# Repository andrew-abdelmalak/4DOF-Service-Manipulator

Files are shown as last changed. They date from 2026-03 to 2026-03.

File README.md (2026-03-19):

# 4-DOF Service Robotic Manipulator for Automated Beverage Preparation








<p align="center">
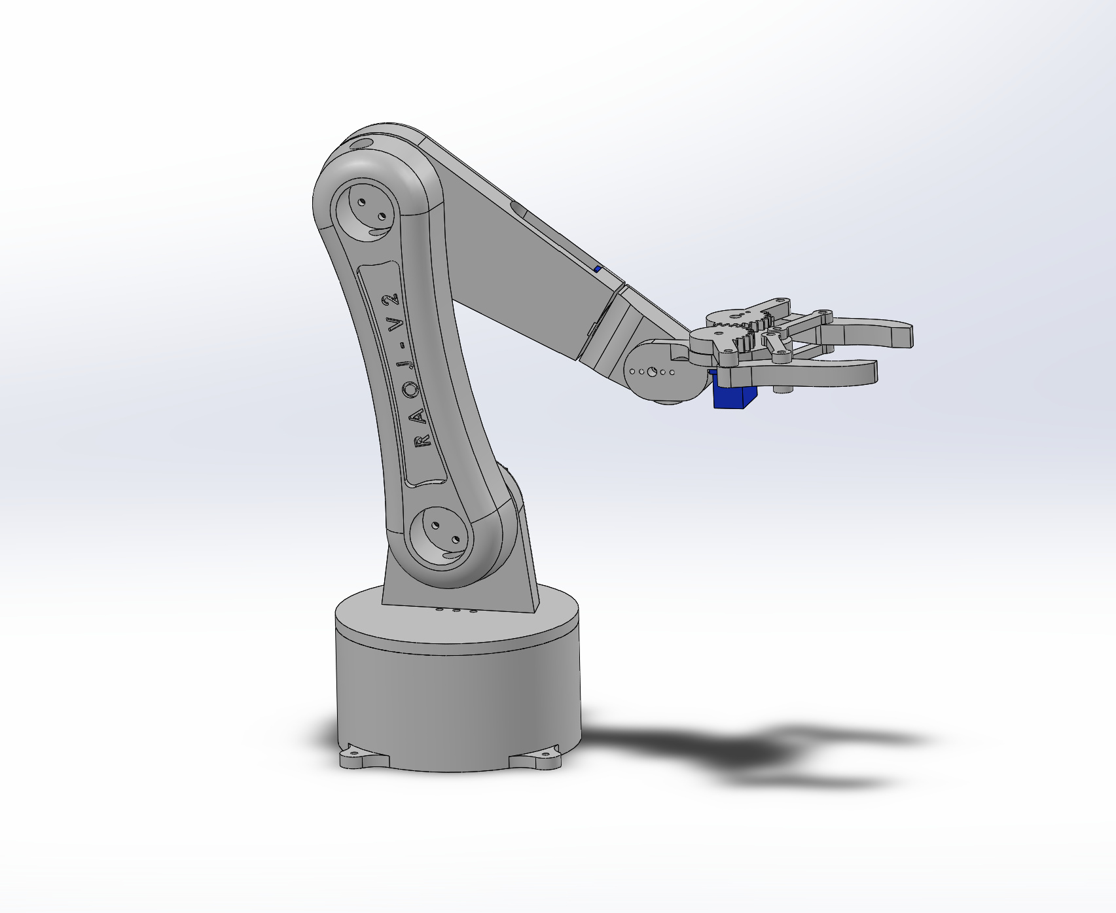
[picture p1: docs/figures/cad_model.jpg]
CAD model of the 4-DOF robotic manipulator
  
</p>

A desktop-scale **4-DOF service robotic manipulator** designed for **automated beverage preparation**. The system covers the full robotics development pipeline — from DH-based kinematic modeling through dual-platform simulation (Gazebo + Simscape) to physical hardware execution on a 3D-printed arm.

The robot performs a complete **tea-preparation demo**: sugar transport, spoon manipulation, and stirring — demonstrating coordinated multi-step service tasks using open-loop trajectory control.

> **Paper:** The full IEEE-format technical report is available in [`docs/4DOF_Service_Manipulator.pdf`](docs/4DOF_Service_Manipulator.pdf).

---

## Table of Contents

- [Overview](#overview)
- [System Architecture](#system-architecture)
- [Simulation & Results](#simulation--results)
- [Tea-Preparation Demo](#tea-preparation-demo)
- [Repository Structure](#repository-structure)
- [Getting Started](#getting-started)
- [Authors](#authors)
- [License](#license)

---

## Overview

The manipulator has 5 revolute joints (4 active DOF + 1 gripper joint), constructed from **3D-printed PLA** and actuated by **MG996R** (high-torque) + **SG90** (micro) servo motors. Control is handled by an Arduino Uno communicating with a PC-based trajectory planner over serial (115 200 baud).

<p align="center">
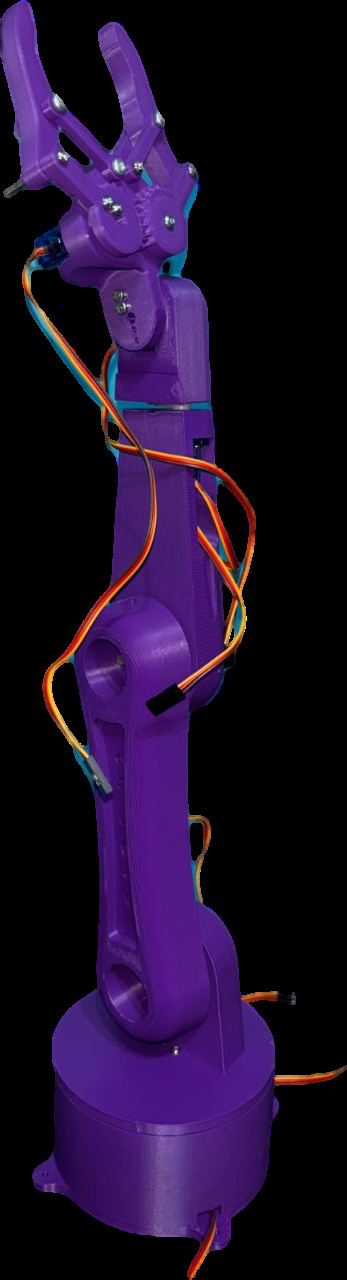
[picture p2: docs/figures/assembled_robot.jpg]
Fully assembled 4-DOF manipulator
  
</p>

### DH Parameters

Coordinate frames follow the Denavit–Hartenberg convention with the X–Z rule.

<p align="center">
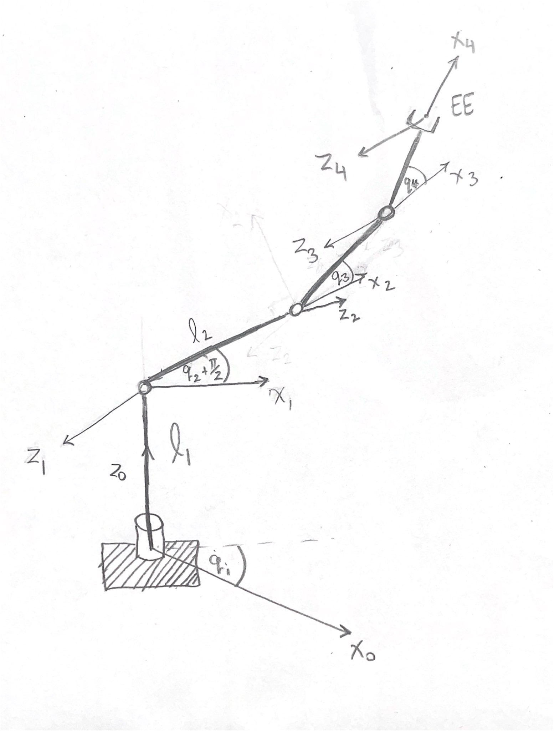
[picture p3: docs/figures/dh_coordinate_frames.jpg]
DH coordinate frame assignment
  
</p>

| Link | θᵢ | dᵢ (m) | aᵢ (m) | αᵢ (rad) |
|---|-----|---|---|---|
| 1 | q₁ + π/2 | 0.04355 | 0 | π/2 |
| 2 | q₂ | 0 | 0.140 | π |
| 3 | q₃ | 0 | 0.133 | π |
| 4 | q₄ | 0 | 0.109 | 0 |

### Key Results

| Metric | Value |
|---|---|
| FK roundtrip positional error | 0.000 m |
| IK roundtrip velocity error | ~10⁻¹⁵ (machine precision) |
| Zero-config end-effector height | 0.4255 m (= d₁ + a₂ + a₃ + a₄) |
| Trajectory sampling period | 0.1 s |
| IK damping factor (λ) | 0.05 |

---

## System Architecture

| Component | Qty | Role |
|---|-----|---|
| 3D-printed PLA parts | 1 set | Arm structure |
| MG996R servo motors | 3 | Base, shoulder, elbow (high-torque) |
| SG90 micro servos | 3 | Wrist, gripper, fixed pivot |
| Arduino Uno | 1 | PWM servo control |
| 12 V DC power supply | 1 | Motor power |

<p align="center">
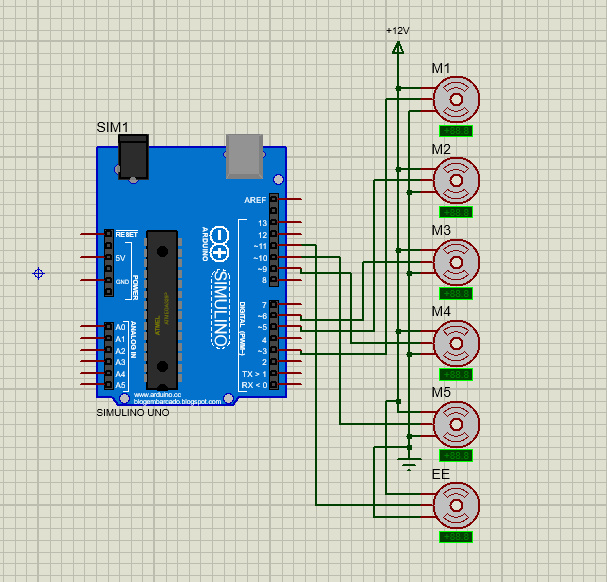
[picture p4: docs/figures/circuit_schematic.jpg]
Circuit schematic
  
</p>

**Communication protocol:** The PC-based trajectory planner sends comma-separated joint angles (`"J1,J2,J3,J4\n"`) over serial at 115 200 baud. The Arduino responds with `"READY\n"` after each command to ensure motion synchronization. Dedicated `GRIPPER_OPEN` / `GRIPPER_CLOSE` commands control the end-effector.

---

## Simulation & Results

Kinematic models and trajectories were validated on two independent simulation platforms, plus physical hardware:

<p align="center">
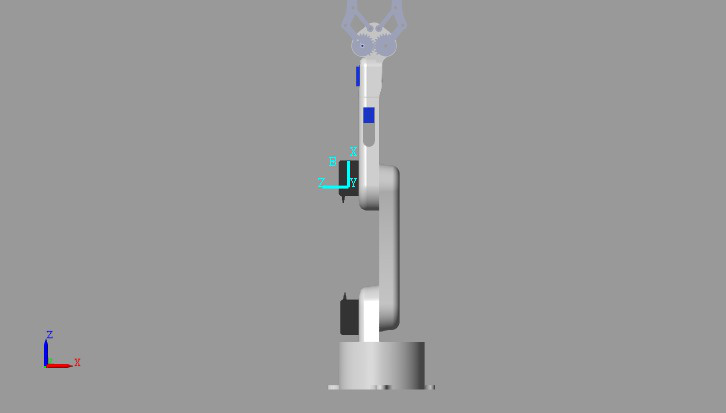
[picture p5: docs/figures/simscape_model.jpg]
Simscape Multibody model
  
  &nbsp;&nbsp;
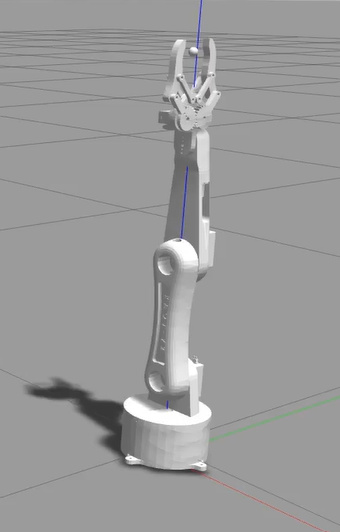
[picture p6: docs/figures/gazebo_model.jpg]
Gazebo simulation
  
</p>
<p align="center"><em>Left: Simscape Multibody &nbsp;|&nbsp; Right: Gazebo/ROS</em></p>

**Trajectory validation** — both square (pick-and-place) and circular (stirring) trajectories were executed across all platforms with high fidelity:

<p align="center">
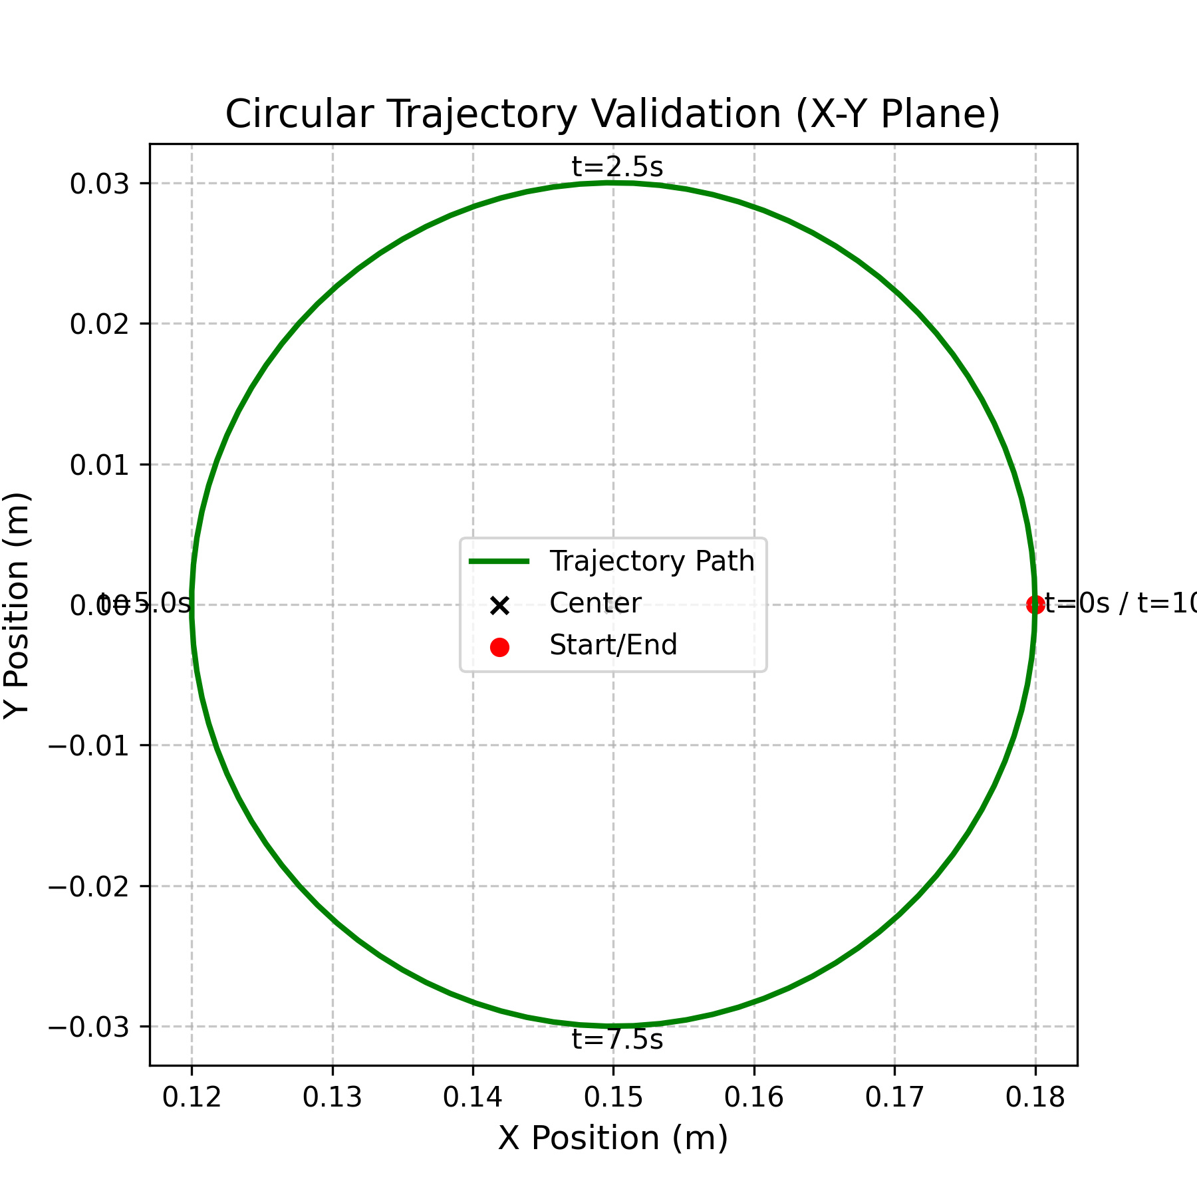
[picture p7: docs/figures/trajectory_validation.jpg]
Circular trajectory validation
  
  &nbsp;&nbsp;
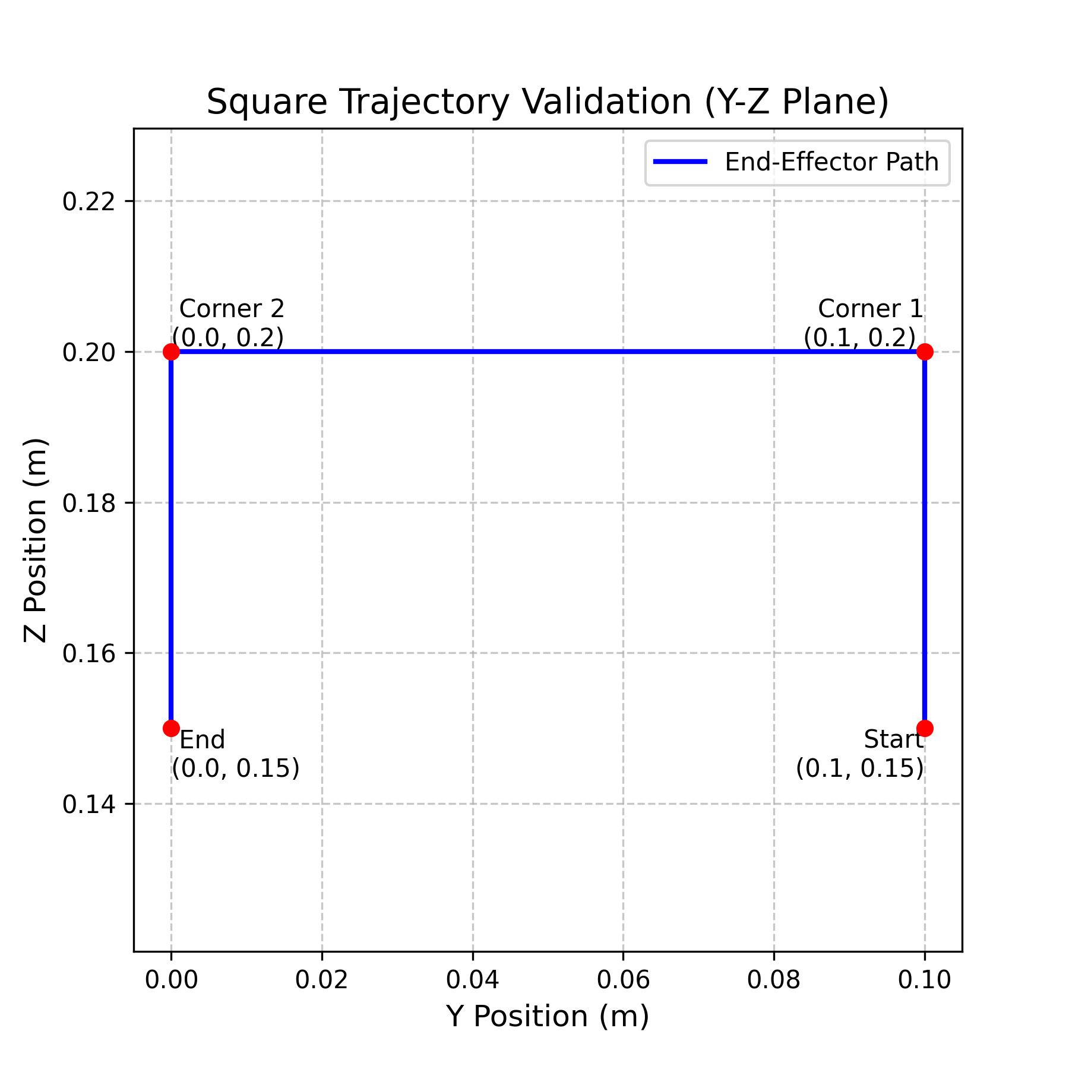
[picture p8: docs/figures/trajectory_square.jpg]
Square trajectory validation
  
</p>
<p align="center"><em>Left: Circular trajectory &nbsp;|&nbsp; Right: Square trajectory</em></p>

| Test | Input q (rad) | ‖q_rec − q‖ | ‖q̇_rec − q̇‖ |
|---|---|---|---|
| Case 1 | [0, 0, 0, 0] | 0.000 | 0.000 |
| Case 2 | [0.2, 0.4, −0.3, 0.1] | 0.000 | 1.38×10⁻¹⁵ |
| Case 3 | [−0.3, 0.6, 0.2, −0.2] | 0.000 | 5.49×10⁻¹⁶ |

---

## Tea-Preparation Demo

The primary validation task demonstrates coordinated task-space motion and gripper actuation across five sequential phases:

| Phase | Motion | Points | Description |
|---|---|---|---|
| 1 | Square path 1 | 104 | Pick up sugar cube, transport to cup, release |
| 2 | Square path 2 | 104 | Move end-effector to spoon and grasp handle |
| 3 | Reverse square | 104 | Lift spoon, transport toward cup |
| 4 | Linear transition | 42 | Center spoon inside cup |
| 5 | Circular stirring | 102 × 3 | Stir for three full cycles (30 s total) |

<p align="center">
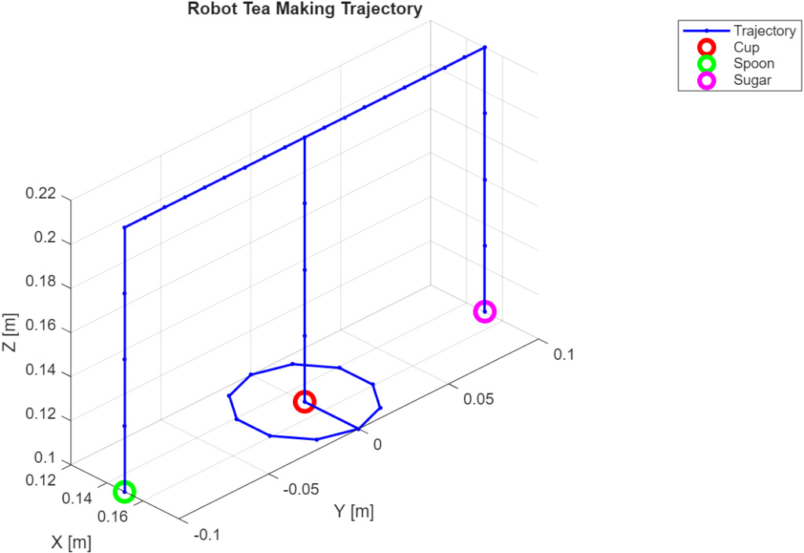
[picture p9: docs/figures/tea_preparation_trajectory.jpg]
3D tea-preparation trajectory visualization
  
</p>
<p align="center"><em>3D visualization of the complete tea-preparation trajectory showing waypoints for sugar transport, spoon approach, and stirring.</em></p>

---

## Repository Structure

```
├── simulation/
│   ├── ros/src/                        # ROS/Gazebo simulation
│   │   └── my_robot_gazebo/            # ROS package
│   │       ├── urdf/robot.urdf         # Robot description
│   │       ├── launch/                 # Gazebo launch files
│   │       ├── meshes/                 # STL mesh files
│   │       ├── config/                 # Controller configs
│   │       ├── scripts/                # Python nodes (FK, IK, trajectory)
│   │       ├── models/                 # Gazebo world models
│   │       └── worlds/                 # Gazebo world files
│   │
│   └── matlab/                         # MATLAB/Simulink
│       ├── kinematics/                 # FK, IK, Jacobian functions
│       ├── trajectory/                 # Trajectory planners + CSV data
│       ├── simscape/                   # Simulink Simscape Multibody model
│       └── tests/                      # Validation scripts
│
├── hardware/
│   ├── arduino/                        # Arduino servo control
│   │   ├── receiver/receiver.ino       # Arduino firmware
│   │   ├── send_trajectory.py          # PC → Arduino trajectory sender
│   │   └── trajectories/              # Pre-computed CSV joint angles
│   │
│   ├── cad/                            # SolidWorks CAD exports
│   │   ├── 5_DOF_Robot_Assembly.SLDASM # Full assembly
│   │   └── *.STEP                      # Individual part files
│   └── actuator_connections.pdsprj     # Proteus circuit simulation
│
├── docs/
│   ├── 4DOF_Service_Manipulator.pdf    # Full IEEE-format technical report
│   └── figures/                        # Figures from the report
│
├── .gitignore
├── LICENSE
├── README.md
└── requirements.txt
```

---

## Getting Started

### Prerequisites

| Tool | Version | Purpose |
|---|---|---|
| ROS Noetic | Ubuntu 20.04 | Gazebo simulation |
| MATLAB | R2023b+ | Kinematics + Simscape |
| Python | 3.8+ | ROS nodes + Arduino comm |
| Arduino IDE | 2.0+ | Firmware upload |

### Python Environment

```bash
python -m venv .venv
source .venv/bin/activate        # Linux/macOS
# .venv\Scripts\activate         # Windows
pip install -r requirements.txt
```

### ROS / Gazebo

```bash
mkdir -p ~/catkin_ws/src
ln -s /path/to/this/repo/simulation/ros/src/my_robot_gazebo ~/catkin_ws/src/
cd ~/catkin_ws && catkin_make && source devel/setup.bash

# Launch robot in Gazebo
roslaunch my_robot_gazebo spawn_gazebo.launch

# Run trajectory execution (separate terminal)
rosrun my_robot_gazebo trajectory_node.py
```

### MATLAB / Simulink

```matlab
addpath('simulation/matlab/kinematics');
addpath('simulation/matlab/trajectory');
addpath('simulation/matlab/tests');

test_forward_position     % FK validation
test_inverse_kinematics   % IK validation
test_velocity_kinematics  % Jacobian validation

% Open Simscape model
open('simulation/matlab/simscape/x5_DOF_Robot_Assembly.slx')
```

See [`simulation/matlab/README.md`](simulation/matlab/README.md) for detailed usage.

### Arduino Hardware

1. Upload `hardware/arduino/receiver/receiver.ino` to the Arduino Uno
2. Connect servos to PWM pins (Base→3, Shoulder→5, Elbow→6, Wrist→9, Gripper→10)
3. Set the serial port in `send_trajectory.py` (`/dev/cu.usbserial-110` on macOS, `COM3` on Windows)
4. Run: `python hardware/arduino/send_trajectory.py`

See [`hardware/arduino/README.md`](hardware/arduino/README.md) for detailed setup, calibration, and troubleshooting.

---

## Authors

| Name | Affiliation |
|---|---|
| **Andrew Abdelmalak** | Mechatronics Engineering, GUC |
| **Daniel Boules** | Mechatronics Engineering, GUC |
| **David Girgis** | Mechatronics Engineering, GUC |
| **Kirolous Kirolous** | Mechatronics Engineering, GUC |
| **Samir Yacoub** | Mechatronics Engineering, GUC |
| **Youssef Salama** | Mechatronics Engineering, GUC |

---

## Acknowledgments

This project was developed as part of the Mechatronics Engineering program at the German University in Cairo (GUC).

---

## References

1. S. Park *et al.*, "Robot versus human barista: Comparison of volatile compounds and consumers' acceptance, sensory profile, and emotional response of brewed coffee," *Food Research International*, vol. 172, p. 113119, 2023.
2. A. Setiawan and A. Ma'arif, "Stirring system design for automatic coffee maker using OMRON PLC and PID control," *Int. J. Robotics and Control Systems*, vol. 1, no. 1, pp. 1–8, 2021.
3. M. Michalková *et al.*, "Automating the handling process of a coffee machine using a robotic manipulator," in *Proc. IEEE Int. Conf. ETFA*, 2024.
4. H. P. Nurba *et al.*, "Performance evaluation of 3 DOF arm robot with forward kinematics Denavit–Hartenberg method," in *Proc. IEEE TSSA*, 2022.
5. H. D. Salman, M. N. Hamzah, and S. H. Bakhy, "Kinematics analysis and implementation of three degrees of freedom robotic arm by using MATLAB," *The Iraqi Journal for Mechanical and Material Engineering*, vol. 21, no. 2, pp. 118–129, 2021.
6. M. A. Saad *et al.*, "Development of an automated coffee preparation system using a robotic manipulator," *J. Mechatronics, Robotics, and Systems Programming*, vol. 31, no. 38, pp. 45–52, 2024.
7. A. Waluyo *et al.*, "Robot arm design for coffee maker Arduino based," in *Proc. 2nd Borobudur Int. Symposium on Science and Technology*, Atlantis Press, 2021, pp. 438–442.
8. J. J. Craig, *Introduction to Robotics: Mechanics and Control*, 3rd ed. Pearson Prentice Hall, 2005.
9. B. Siciliano *et al.*, *Robotics: Modelling, Planning and Control*. Springer, 2009.

---

## License

MIT — see [LICENSE](LICENSE).

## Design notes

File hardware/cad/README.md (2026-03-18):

# CAD Files

SolidWorks CAD design files for the 4-DOF service robotic manipulator.

## Assembly

- **`5_DOF_Robot_Assembly.SLDASM`** — Full SolidWorks assembly (requires SolidWorks 2020+)

## Part Files (STEP)

Individual part exports in STEP format (universal, compatible with any CAD software):

| Part | Description |
|---|---|
| Base Link | Stationary base housing the MG996R base servo |
| Arm 1 (Shoulder) | First link driven by the shoulder servo |
| Arm 2 (Elbow) | Second link driven by the elbow servo |
| Arm 3 (Wrist) | Wrist link driven by SG90 micro servo |
| Gripper | Parallel-jaw gripper with friction-lined inner surfaces |
| Rotating Waste | Fixed pivot component (maintains 4-DOF kinematic chain) |

## Manufacturing

- **Material:** PLA (3D-printed on FDM printer)
- **Servos:** 3× MG996R (base, shoulder, elbow) + 3× SG90 (wrist, gripper, fixed pivot)
- **Assembly:** Servo horns press-fit into 3D-printed brackets; base secured to weighted wooden board

## Mesh Exports

STL mesh files used for Gazebo/RViz visualization are located at:

```
simulation/ros/src/my_robot_gazebo/meshes/
```

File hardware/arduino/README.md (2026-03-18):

# 🤖 Tea-Making Robot Arm - User Guide

## 📋 Overview

This project controls a **4-DOF (4 Degrees of Freedom) robotic arm** designed to perform automated tea-making tasks. The robot features **4 joints** for precise movement and a **gripper** (not counted as a DOF) for object manipulation.

### Robot Specifications
- **Degrees of Freedom:** 4 (Joints 1-4)
- **End Effector:** 1 Gripper (Joint 5)
- **Control:** Serial communication via Arduino
- **Function:** Automated tea preparation and serving

---

## 🎯 System Components

### Hardware
1. **Arduino Board** (with servo connections)
2. **5 Servo Motors:**
   - Joint 1-4: Robot arm movement (4-DOF)
   - Joint 5: Gripper for grasping objects
3. **USB Cable** for Arduino-to-Computer connection

### Software Files
1. **`receiver.ino`** - Arduino firmware (runs on Arduino)
2. **`send_trajectory.py`** - Python trajectory controller (runs on computer)
3. **CSV Trajectory Files** (in `trajectories/` folder):
   - `trajectory_data_combined_1_square1.csv`
   - `trajectory_data_combined_2_square2.csv`
   - `trajectory_data_combined_3_square2_rev.csv`
   - `trajectory_data_combined_4_transition.csv`
   - `trajectory_data_combined_5_circle.csv`

---

## 🚀 Setup Instructions

### Step 1: Upload Arduino Firmware

1. **Open Arduino IDE**
   - Download from [arduino.cc](https://www.arduino.cc/en/software) if not installed

2. **Open the receiver sketch**
   - File → Open → Navigate to `receiver/receiver.ino`

3. **Select your Arduino board**
   - Tools → Board → Select your Arduino model (e.g., Arduino Uno)

4. **Select the correct port**
   - Tools → Port → Select the port with your Arduino
   - Windows: `COM3`, `COM4`, etc.
   - Mac/Linux: `/dev/cu.usbserial-110` or similar

5. **Upload the code**
   - Click the **Upload** button (→) or press `Ctrl+U` (Windows) / `Cmd+U` (Mac)
   - Wait for "Done uploading" message

6. **Verify connection**
   - Open Serial Monitor (Tools → Serial Monitor)
   - Set baud rate to **115200**
   - You should see: `ARDUINO_CONNECTED`

---

### Step 2: Run the Python Trajectory Controller

#### Prerequisites
Make sure you have Python 3 installed with the required library:
```bash
pip install pyserial
```

#### Configuration
1. **Open `send_trajectory.py`** in a text editor
2. **Update the serial port** (lines 7-9) to match your Arduino port:
   ```python
   SERIAL_PORT = '/dev/cu.usbserial-110'  # Mac/Linux
   # or
   SERIAL_PORT = 'COM3'  # Windows
   ```

#### Running the Program
1. **Open a terminal/command prompt** in the `` directory

2. **Run the script:**
   ```bash
   python send_trajectory.py
   ```

3. **Expected sequence:**
   - Script connects to Arduino
   - Loads 5 trajectory CSV files
   - Executes the tea-making sequence automatically

---

## 🎬 Tea-Making Sequence

The robot performs the following automated sequence:

### **Phase 1: Square 1 - Pick Tea Bag** (104 points)
1. 🟢 **Opens gripper**
2. 📍 **Moves to pickup position**
3. 🔴 **Closes gripper** (grabs tea bag)
4. 🚶 **Moves tea bag** along square trajectory
5. 🟢 **Opens gripper** (releases tea bag into cup)

### **Phase 2: Square 2 - Reposition** (104 points)
1. 🚶 **Moves to new location** (gripper open)
2. 🔴 **Closes gripper** (prepares for next task)

### **Phase 3: Square 2 Reverse - Return** (104 points)
1. 🚶 **Returns along reverse path** (gripper closed)

### **Phase 4: Transition - Prepare for Stirring** (42 points)
1. 🚶 **Transitions to stirring position** (gripper closed)

### **Phase 5: Circle - Stir Tea** (102 points × 3 repetitions)
1. 🔁 **Performs circular stirring motion** 3 times
2. ⚡ **Faster speed** for efficient stirring

**Total Execution Time:** ~49 seconds

---

## ⚙️ Gripper Configuration

### Safety Settings
The gripper is configured to prevent motor overload:

```cpp
GRIPPER_OPEN = 90.0°     → Servo: 180° (fully open)
GRIPPER_CLOSED = 30.0°   → Servo: 120° (safe grip)
GRIPPER_MIN_SAFE = 30.0° → Safety limit
```

### Adjusting Grip Strength
If objects are slipping or motor is struggling, edit `receiver.ino`:

**For tighter grip:**
```cpp
const float GRIPPER_CLOSED = 15.0;  // Tighter (Servo: 105°)
```

**For gentler grip:**
```cpp
const float GRIPPER_CLOSED = 40.0;  // Gentler (Servo: 130°)
```

⚠️ **Warning:** Never set below 10° to avoid motor damage!

---

## � Trajectory File Format

Each CSV file contains joint angles (in degrees):
```
J1, J2, J3, J4
33.65, -4.69, 57.08, -89.94
...
```

**Column Layout:**
- **Column 1:** Joint 1 angle (degrees)
- **Column 2:** Joint 2 angle (degrees)
- **Column 3:** Joint 3 angle (degrees)
- **Column 4:** Joint 4 angle (degrees)

The gripper is controlled separately via commands, not trajectory files.

---

## � Troubleshooting

### Arduino Not Found
- Check USB connection
- Verify correct port in Arduino IDE and `send_trajectory.py`
- Try unplugging and reconnecting Arduino

### Python Script Errors
**"Could not open port":**
- Close Arduino Serial Monitor before running script
- Update `SERIAL_PORT` in `send_trajectory.py`

**"Module not found (serial)":**
```bash
pip install pyserial
```

### Gripper Issues
**Not gripping tightly enough:**
- Reduce `GRIPPER_CLOSED` angle (e.g., from 30° to 15°)

**Motor struggling/buzzing:**
- Increase `GRIPPER_CLOSED` angle (e.g., from 15° to 40°)

### Trajectory Issues
**Robot jerky movement:**
- Increase `DELAY_BETWEEN_POINTS` in `send_trajectory.py` (line 15)

**CSV file not found:**
- Ensure all CSV files are in `trajectories/` folder
- Check file names match exactly

---

## 🎛️ Customization

### Modify Speed
Edit `send_trajectory.py`:
```python
DELAY_BETWEEN_POINTS = 0.1  # Slower: increase (e.g., 0.2)
CIRCLE_DELAY = 0.05         # Faster stirring: decrease (e.g., 0.03)
```

### Change Trajectory
Replace CSV files in `trajectories/` folder with your own trajectory data. Maintain the same format (4 columns for Joint 1-4).

### Add New Phases
Edit `send_trajectory.py` to add more CSV files and execution steps following the existing pattern.

---

## 📝 Technical Details

### Communication Protocol
- **Baud Rate:** 115200
- **Command Format:**
  - Joint angles: `J1,J2,J3,J4\n`
  - Gripper open: `GRIPPER_OPEN\n`
  - Gripper close: `GRIPPER_CLOSE\n`
- **Acknowledgment:** Arduino sends `READY` after each command

### Joint Calibration
Each joint has specific calibration offsets (see `receiver.ino`):
- **Joint 1:** Direct mapping + 90° offset
- **Joint 2:** Inverted + 110° offset
- **Joint 3:** Inverted + 90° offset
- **Joint 4:** Inverted + 110° offset
- **Gripper:** Direct mapping + 90° offset

---

## 📞 Support

For issues or questions:
1. Check the Troubleshooting section
2. Verify all connections and settings
3. Review serial monitor output for error messages

---

## 🏆 Project Summary

This 4-DOF robotic tea maker demonstrates:
- ✅ Automated trajectory execution
- ✅ Precise gripper control
- ✅ Multi-phase task sequencing
- ✅ Safe motor operation
- ✅ Serial communication between Arduino and Python

**Enjoy your automated tea! ☕🤖**

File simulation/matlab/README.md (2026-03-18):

# MATLAB / Simulink Simulation

MATLAB-based kinematic modeling, trajectory planning, and Simscape Multibody simulation for the 4-DOF manipulator.

## Directory Layout

```
matlab/
├── kinematics/        # Core kinematic functions
├── trajectory/        # Trajectory planners and data generation
├── simscape/          # Simulink Simscape Multibody model
└── tests/             # Validation scripts
```

## Quick Start

```matlab
% Add all paths
addpath('kinematics');
addpath('trajectory');
addpath('tests');
```

## Running Tests

The test suite validates FK, IK, and velocity kinematics across multiple joint configurations.

```matlab
% 1. Generate the symbolic FK function (required once)
run_fk_4dof

% 2. Validate forward kinematics
test_forward_position       % Zero-config → [0, 0, 0.4255] m

% 3. Validate inverse kinematics
test_inverse_kinematics     % FK → IK roundtrip, ‖q_rec − q‖ = 0

% 4. Validate velocity kinematics
test_velocity_kinematics    % FK/IK velocity roundtrip, error ~10⁻¹⁵
```

## Kinematics Functions

| Function | Description |
|---|---|
| `forward_kinematics_func.m` | Coder-compatible FK: `(q1,q2,q3,q4) → [x,y,z]` |
| `transformation_func.m` | Standard DH transformation matrix (numeric + symbolic) |
| `jacobian_matrix.m` | 6×4 geometric Jacobian |
| `inverse_kinematics_func.m` | Newton–Raphson IK solver (DLS, λ = 0.05) |
| `inverse_kinematics_with_orientation.m` | IK with wrist orientation constraint |
| `forward_velocity_kinematics.m` | V = J(q) · q̇ |
| `get_transform_matrix.m` | Full 4×4 homogeneous transform for orientation |

## Trajectory Planning

| Script | Description |
|---|---|
| `movement_generation.m` | Full tea-preparation sequence (5 phases) → `robot_tea_data.mat` |
| `square_trajectory.m` | 5 cm × 5 cm square path with TimeSeries output |
| `generate_simulink_data.m` | Circular trajectory for Simscape → `trajectory_data.mat` |

## Simscape Model

Open the Simulink model:

```matlab
open('simscape/x5_DOF_Robot_Assembly.slx')
```

The CAD assembly is imported via `x5_DOF_Robot_Assembly_DataFile.m` which contains rigid transforms, joint definitions, and solid body properties for all 13 bodies.

## DH Parameters

| Link | θᵢ | dᵢ (m) | aᵢ (m) | αᵢ (rad) |
|---|-----|---|---|---|
| 1 | q₁ + π/2 | 0.04355 | 0 | π/2 |
| 2 | q₂ | 0 | 0.140 | π |
| 3 | q₃ | 0 | 0.133 | π |
| 4 | q₄ | 0 | 0.109 | 0 |

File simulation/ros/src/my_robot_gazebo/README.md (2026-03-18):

# my_robot_gazebo (ROS Noetic + Gazebo Classic)

This package lets you spawn your **URDF** robot in Gazebo quickly, without scaling changes.

## 1) Drop your files
- Put your URDF at: `urdf/robot.urdf` (rename your file to `robot.urdf` or update the launch arg `urdf_file`).
- Put all mesh files under: `meshes/`. Keep the same relative paths used in your URDF.
  - Mesh references inside URDF should look like: `filename="package://my_robot_gazebo/meshes/<your_mesh.stl or dae>"`

> **Note:** No scaling is applied. If your meshes were exported with real dimensions, they will be used as-is.

## 2) Build in a Catkin workspace
```bash
# If you don't have a workspace yet:
mkdir -p ~/catkin_ws/src
cd ~/catkin_ws/src
# Copy or unzip this package into src/
# e.g., cp -r /path/to/my_robot_gazebo .
cd ..
catkin_make
source devel/setup.bash
# For convenience, add to your ~/.bashrc:
# echo "source ~/catkin_ws/devel/setup.bash" >> ~/.bashrc
```

## 3) Spawn in Gazebo
```bash
roslaunch my_robot_gazebo spawn_gazebo.launch
```
- To use a different URDF file name:
```bash
roslaunch my_robot_gazebo spawn_gazebo.launch urdf_file:=$(rospack find my_robot_gazebo)/urdf/YOUR_FILE.urdf
```
- Adjust initial pose:
```bash
roslaunch my_robot_gazebo spawn_gazebo.launch x:=1.0 y:=2.0 z:=0.2 Y:=1.57
```

## 4) Quick RViz check (no Gazebo)
```bash
roslaunch my_robot_gazebo view_model.launch
```

## Troubleshooting
- **Meshes not showing**: Ensure URDF uses `package://my_robot_gazebo/meshes/...` and the files exist.
- **xacro error**: Even with plain URDF, `xacro` can parse it. If it fails, change:
  - In launch files, replace `$(find xacro)/xacro $(arg urdf_file)` with `cat $(arg urdf_file)`.
- **Collisions/inertias**: Gazebo needs valid `<inertial>` and `<collision>` for each link for stable physics.
- **Gazebo not installed**: Use `sudo apt install ros-noetic-gazebo-ros-pkgs ros-noetic-gazebo-ros-control`.

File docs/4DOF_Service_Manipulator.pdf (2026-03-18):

# Design, Kinematic Analysis, and Experimental Validation of a 4-DOF Service Robotic Manipulator for Automated Beverage Preparation

Andrew Abdelmalak
Dept. of Mechatronics Engineering German University in Cairo (GUC) Cairo, Egypt

Daniel Boules
Dept. of Mechatronics Engineering German University in Cairo (GUC) Cairo, Egypt

David Girgis
Dept. of Mechatronics Engineering German University in Cairo (GUC) Cairo, Egypt

Kirolous Kirolous
Dept. of Mechatronics Engineering German University in Cairo (GUC) Cairo, Egypt

Samir Yacoub
Dept. of Mechatronics Engineering German University in Cairo (GUC) Cairo, Egypt

Youssef Salama
Dept. of Mechatronics Engineering German University in Cairo (GUC) Cairo, Egypt

Abstract—This paper presents the complete design, kinematic analysis, simulation, and experimental validation of a desktopscale 4-DOF service robotic manipulator for automated beverage preparation. The manipulator is constructed from 3D-printed PLA components and actuated by three MG996R high-torque servos and three SG90 micro servos. Kinematic modeling follows the Denavit–Hartenberg convention with link lengths d1 = 0.04355 m, a2 = 0.140 m, a3 = 0.133 m, and a4 = 0.109 m. A numerical inverse kinematics solver based on the Newton– Raphson method with Damped Least-Squares regularization (λ = 0.05) achieves positional errors on the order of 10⁻¹⁵ m in roundtrip validation. Two task-space trajectories—a three-sided square path for pick-and-place operations and a circular path for stirring—are implemented and validated across Gazebo, Simscape Multibody, and physical hardware platforms. A tea-preparation demonstration involving sugar transport, spoon manipulation, and stirring confirms the system’s capability for coordinated multi-step service tasks, demonstrating the viability of accessible, educational-grade manipulators for practical service applications.
Index Terms—Service robotics, robotic manipulator, Denavit– Hartenberg convention, inverse kinematics, trajectory planning, beverage preparation, 3D printing, Gazebo, Simscape.
I. INTRODUCTION

Service robotics is increasingly transforming customeroriented industries by automating tasks that demand consistency, hygiene, and precision. Among these applications, beverage preparation has emerged as a key domain where robots can deliver uniform quality while reducing human workload [1]. Recent studies have demonstrated the growing acceptance of robotic baristas and automated food preparation systems, where robots are valued for their ability to operate continuously without fatigue.
Several robotic coffee preparation systems have been proposed. Setiawan and Ma’arif [2] developed a PLC-based coffee-stirring system with PID control, demonstrating how controlled motion improves drink uniformity and prevents spillage. Michalkova et al. [3] automated an espresso machine ´ using a FANUC industrial arm and PLC logic, validating high-precision manipulators in cafe settings. Nurba et al. [4] ´ developed a 3-DOF manipulator applying Denavit–Hartenberg (DH) forward kinematics, achieving repeatability deviations below 0.06 mm. Salman et al. [5] employed the DH convention to model a 3-DOF arm with MATLAB GUI simulation and Arduino-based actuation. Saad et al. [6] designed an automated coffee preparation system with a robotic manipulator, while Waluyo et al. [7] demonstrated an Arduino-based robot arm for coffee preparation.
However, most existing systems either target industrialscale automation or are limited to single-function prototypes. Limited attention has been given to compact, educational-grade manipulators tailored for multi-step service applications using accessible components. This paper addresses this gap through five contributions:
1) Design and fabrication of a 4-DOF desktop manipulator using 3D-printed parts and locally sourced servos.
2) Complete DH-based kinematic modeling including forward kinematics, numerical inverse kinematics, and velocity kinematics with analytical Jacobian derivation.
3) Dual-platform simulation validation in both Gazebo (ROS-integrated) and MATLAB Simscape Multibody.
4) Task-space trajectory planning with square (pick-andplace) and circular (stirring) paths.
5) Experimental validation on physical hardware through a tea-preparation demonstration.

II. SYSTEM DESIGN

A. Mechanical Architecture

The manipulator possesses 4 Degrees of Freedom (DOF) and is constructed primarily from 3D-printed PLA parts, ensuring a lightweight yet rigid structure (Fig. 1). The arm is actuated by six servo motors: three high-torque MG996R (180◦
, metal gear) servos for the base, shoulder, and elbow joints, and three SG90 micro servos (180◦
, plastic gear) for
the wrist and gripper. One SG90 servo serves as a fixed dummy pivot to maintain the 4-DOF kinematic chain. Table I summarizes the primary components.

TABLE I: Hardware Components

Component | Qty
3D Printed Parts (PLA) | 1 set
MG996R Servo Motors | 3
SG90 Micro Servos | 3
Arduino Uno | 1
Power Supply (12V) | 1
B. End-Effector Design

A parallel gripper serves as the primary end-effector, providing sufficient range and gripping force for lightweight objects such as cups and utensils. The inner surfaces of the jaws are lined with high-friction material to ensure stable grasping. The same gripper can hold a teaspoon attachment for instant beverage preparation, dispensing coffee powder or sugar before stirring—preserving modularity without additional toolchanging mechanisms.

C. Electronics and Communication

The system is powered by a 12V DC supply with a DC-DC step-down converter for voltage regulation. Control logic is executed on an Arduino Uno, which generates PWM signals to control servo positions. Communication between the PC-based trajectory planner and the Arduino operates at 115,200 baud using comma-separated joint angle strings (e.g., "90,45,-30,0") with dedicated gripper commands
(GRIPPER_OPEN, GRIPPER_CLOSE). A handshake proto-
col using a "READY" acknowledgment signal ensures motion synchronization. Table II summarizes the pin assignments.

TABLE II: Arduino Pin Assignments and Calibration

Joint | Pin | Calibration
Base (J1) | 3 | q + 90◦
Shoulder (J2) | 5 | −q + 110◦
Elbow (J3) | 6 | −q + 90◦
Wrist (J4) | 9 | −q + 110◦
Gripper | 10 | q + 90◦ (clamped)


Fig. 1: CAD model of the 4-DOF robotic manipulator showing the joint arrangement and structural proportions.

III. KINEMATIC MODELING

A. Coordinate Frames and DH Parameters

Coordinate frames were assigned following the Denavit– Hartenberg convention [8], [9] using the X–Z rule (Fig. 2). The axes x1, x2, and x3 lie in the same plane, while z1 and z4 are parallel. The z3 axis is oriented opposite to z1 and z4, consistent with the DH convention for this manipulator. The resulting DH parameters are listed in Table III.


Fig. 2: Denavit–Hartenberg coordinate frame assignment for the 4-DOF manipulator.

TABLE III: Denavit–Hartenberg Parameters

Link | θi | di (m) | ai (m) | αi (rad)
1 | q1 + π/2 | 0.04355 | 0 | π/2
2 | q2 | 0 | 0.140 | π
3 | q3 | 0 | 0.133 | π
4 | q4 | 0 | 0.109 | 0
B. Forward Kinematics

The forward kinematics function F(q) computes the end-effector position X = [x, y, z]

| | T
from the joint vector q =
[q1, q2, q3, q4]

T
. Each link transformation is computed using the standard DH matrix:

i−1Ti =

cθi −sθi
cαi
| | sθi
| | sαi | aicθi
sθi | cθi
| cαi | −cθi
sαi | aisθi
0 | sαi | cαi | di
0 | 0 | 0 | 1

(1)

where cθi = cos θi and sθi = sin θi . The global transformation is obtained as 0T4 = 0T1 ·

1T2 ·

2T3 ·

3T4. For the zero joint
configuration (q1 = q2 = q3 = q4 = 0), the end-effector is elevated to z = 0.4255 m along the base z-axis, which equals d1 + a2 + a3 + a4 = 0.04355 + 0.140 + 0.133 + 0.109 m. The FK model was implemented identically in both MATLAB (fk_4dof_demo.m) and Python (ROS node forward_kinematics.py), ensuring consistent results across analytical computation and simulation.
C. Inverse Position Kinematics

Since the manipulator has 4 DOF but operates in 3D Cartesian space (position only), the system is under-actuated for a full 6-DOF pose task. A numerical inverse kinematics solver based on the Newton–Raphson method is employed. The position error is defined as:

ek = Xdes − F(qk) | (2)

The joint angle update uses a Damped Least-Squares (DLS) formulation:

∆q = J

T
v

(q)

Jv(q)J

T
v
(q) + λ

2
I3

−1
e | (3)

where Jv(q) ∈ R

3×4
is the analytical position Jacobian and λ = 0.05 is the damping factor for stability near singularities.
D. Analytical Jacobian

The 3 × 4 position Jacobian Jv(q) = ∂F/∂q was derived analytically. Using l2, l3, l4 for link lengths and shorthand notation s1 = sin q1, c23 = cos(q2+q3), s234 = sin(q2+q3+q4), etc.:

Jv =

−s1Σ −c1Σs −c1Σ

′
s | −l4c1s234
c1Σ | −s1Σs | −s1Σ

′
s | −l4s1s234
0 | Σc | Σ ′ c
l4c234
- (4)

where Σ = l2c2 + l3c23 + l4c234, Σs = l2s2 + l3s23 + l4s234, Σ

′
s = l3s23 + l4s234, Σc = l2c2 + l3c23 + l4c234, and Σ

′
c =

l3c23 + l4c234.

E. Velocity Kinematics
Forward velocity kinematics relates joint velocities q˙ to the end-effector twist V = [vx, vy, vz, ωx, ωy, ωz]

T via the 6 × 4
geometric Jacobian:

V = J(q) · q˙ =

Jv(q)
Jω(q)
q˙ | (5)

The inverse velocity kinematics recovers joint velocities from a desired twist using the pseudo-inverse:

q˙ = J

+(q) · Vdes | (6)

Validation was performed by commanding joint velocities in Gazebo, computing the theoretical end-effector velocity Vtheory = J(q)q˙ , and comparing it against the numerical velocity obtained from finite-difference position measurements. Both values showed close agreement, confirming the correctness of the Jacobian.

IV. TRAJECTORY PLANNING
The trajectory planner generates a sequence of end-effector positions X(t) = [x(t), y(t), z(t)]T
sampled at Ts = 0.1 s.
The IK solver converts these into joint angle sequences q(t).
A. Square Trajectory (Pick-and-Place)
The square trajectory is defined in the Y –Z plane as a three-sided “gate-like” path connecting four waypoints for pick-and-place operations. The motion sequence consists of:
(1) vertical ascent from the pickup location P1 to a safe height P2; (2) horizontal translation at the safe height to the drop-off column P3; and (3) vertical descent to the placement point P4. Position is linearly interpolated between consecutive waypoints:

P(t) = Pstart +

t
Tf
| (Pend − Pstart) | (7)

where Tf = 2 s per segment.

B. Circular Trajectory (Stirring)
The circular trajectory is defined in the X–Y plane for stirring operations. Given center C = [cx, cy, cz] and radius r: θ(t) = 2π

Ttotal

| · t | (8)
x(t) = cx + r cos θ(t) | (9)
y(t) = cy + r sin θ(t) | (10)
z(t) = cz | (constant) | (11)

This ensures smooth continuous motion with constant angular velocity ω = 2π/Ttotal, where Ttotal = 10 s. Table IV summarizes the key planning parameters.

TABLE IV: Trajectory and IK Solver Parameters

Parameter | Value
Sampling time Ts | 0.1 s
Square segment duration Tf | 2 s
Circle total duration Ttotal | 10 s
Damping factor λ | 0.05
IK max iterations | 100
Position tolerance ∥e∥ | 10⁻⁴ m

V. SIMULATION AND VALIDATION
A. Dual-Platform Simulation

The kinematic model and trajectories were validated in two simulation environments: Gazebo (physics-based, ROS-integrated) and Simscape Multibody (system-level, MAT-LAB/Simulink). In Gazebo, a Python ROS node published joint commands to the robot URDF model and subscribed to end-effector poses via the /model_states topic. In Simscape, the CAD assembly was imported into Simulink with MATLAB Function blocks computing FK for direct comparison.
Both environments produced end-effector positions matching the analytical model for all tested configurations. Fig. 3 shows the robot models in both simulation environments.


(a) Simscape Multibody | (b) Gazebo

Fig. 3: Robot models in both simulation environments.

B. Forward Kinematics Verification

Table V presents the FK verification results from MATLAB, showing end-effector positions and velocities for two test configurations. The zero-configuration case yields the expected z = 0.426 m, confirming the DH parameter chain.

TABLE V: MATLAB Kinematic Test Cases

Case Input q (rad) | Output x (m) | Output V
1 | [0, 0, 0, 0] | [0, 0, 0.426] | [0, 0, 0, 0, 0, 0.1]
2 | [0.2, 0.4, −0.3, 0.1] [−0.214, −0.043, 0.350] [−0.081, . . .]
C. Inverse Kinematics Roundtrip Validation

Three roundtrip tests were performed in the ROS/Gazebo environment (Table VI). In each test, a joint vector q was converted to Cartesian position via FK, then recovered via IK. The positional error ∥qrec−q∥ was zero for all cases, while the velocity error ∥q˙ rec−q˙ ∥ was on the order of 10⁻¹⁵, attributable solely to machine-precision floating-point arithmetic.

TABLE VI: ROS/Gazebo Roundtrip Validation

Case Input q (rad) | ∥qrec−q∥ | ∥q˙ rec−q˙ ∥
1 | [0, 0, 0, 0] | 0.000 | 0.000
2 | [0.2, 0.4, −0.3, 0.1] | 0.000 | 1.38×10⁻¹⁵
3 | [−0.3, 0.6, 0.2, −0.2] | 0.000 | 5.49×10⁻¹⁶
D. Trajectory Validation

Both square and circular trajectories were executed in Gazebo and Simscape, with joint-angle sequences generated by the custom Python planner. Fig. 4 shows the trajectory validation results. For the square path, the four corners were traced with high fidelity and distinct transitions between linear segments. For the circular path, the end-effector maintained constant z-height while tracing a nearly perfect circle in the X–Y plane, with small deviations due to discretization and numerical IK residuals. The end-effector traces from Simscape closely matched Gazebo results, confirming cross-platform consistency despite differences in numerical integrators.


(a) Circular trajectory | (b) Square trajectory

Fig. 4: Task-space trajectory validation results from simulation.

VI. HARDWARE IMPLEMENTATION

A. Assembly and Wiring

The physical manipulator was fully assembled from 3D-printed PLA parts with all servo motors mounted at their respective joints (Fig. 6). The robot’s base is secured to a weighted wooden board to prevent tipping during high-speed movements. All electronics, including the Arduino Uno and motor connections, are housed in a protective enclosure. The circuit schematic (Fig. 5) shows the six servo motors connected to the Arduino’s PWM pins, with the 12V external power regulated through a DC-DC converter.


Fig. 5: Circuit schematic: Arduino Uno connected to six servo motors (M1–M5 and EE) via PWM pins, with 12V external power and common ground.

B. Open-Loop Validation

Initial hardware testing used Arduino scripts to sequentially actuate each motor through its full range of motion: base rotation, shoulder link, elbow link, wrist rotation, and gripper actuation. The fixed servo (motor 4) was confirmed stationary, consistent with the 4-DOF design. All active degrees of freedom responded correctly to commands, validating hardware readiness for trajectory execution.

C. Trajectory Execution

The joint-angle sequences computed by the trajectory planner were exported as CSV files and transmitted to the Arduino via a dedicated Python script (send_trajectory.py) that reads files line-by-line and waits for "READY" acknowledgments. The circular trajectory produced smooth, continuous motor movement, validating the 0.1 s time-step resolution. The square trajectory corners were reached with reasonable accuracy, with minor deviations attributed to mechanical backlash in servo gears and arm deflection under gravity at full extension.


Fig. 6: Fully assembled 4-DOF robotic manipulator in the experimental setup.

VII. APPLICATION: TEA PREPARATION

The tea-preparation scenario serves as the primary validation task, demonstrating coordinated task-space motion and gripper actuation in a realistic service context. The complete task consists of five motion phases executed sequentially:

1) Sugar Transport: The manipulator executes the first square trajectory to pick up a sugar cube from its container, transport it, and release it into the cup.

2) Spoon Approach: A second square trajectory moves the end-effector to the spoon location and grasps the spoon handle.
3) Spoon Transport: The arm lifts the spoon and transports it toward the cup using a reverse square path.
4) Linear Centering: A short linear translation centers the spoon within the cup frame before stirring.
5) Stirring: The robot performs the circular trajectory for three full cycles (3 × 10 s), maintaining the spoon vertically inside the cup.
The complete 3D trajectory combining all phases is visualized in Fig. 7, illustrating the spatial relationship between the task objects (sugar container, spoon, cup) and the robot’s path.


Fig. 7: 3D visualization of the complete tea-preparation trajectory, showing waypoints for sugar transport, spoon approach, and stirring.

Qualitatively, the hardware execution matched the simulation behavior. The square corners were clearly visible in the arm motion, and the circular stirring appeared smooth and repeatable. Small deviations from ideal paths arise from servo backlash, link flexibility, open-loop control, and slight misalignments between modeled and actual object positions. Despite these imperfections, the system successfully demonstrated coordinated multi-step manipulation in a practical service task.

VIII. DISCUSSION

The experimental results confirm that a low-cost, 3D-printed 4-DOF manipulator can perform multi-step beverage preparation tasks with acceptable accuracy. The DH-based kinematic model achieves machine-precision accuracy in roundtrip validation, demonstrating that the analytical framework is mathematically sound. The dual-platform simulation approach— validating in both Gazebo and Simscape—provides confidence that the kinematic model generalizes across different physics engines.
The primary limitation of the current system is the open-loop control architecture. Without encoder feedback, the servo motors are susceptible to backlash-induced errors, particularly at the square trajectory corners where direction changes are abrupt. The circular trajectory, being inherently smooth, suffers less from this limitation.
The use of locally sourced components and 3D printing eliminates the need for specialized industrial parts, making this platform accessible for educational institutions and smallscale automation research.

IX. CONCLUSION
This paper presented the complete development cycle of a 4-DOF service robotic manipulator, from mechanical design through kinematic analysis, simulation, and experimental validation. The DH-based kinematic model was verified across MATLAB, ROS/Gazebo, and Simscape with roundtrip errors on the order of 10⁻¹⁵ m. Task-space trajectory planning— using linear interpolation for pick-and-place and parametric equations for stirring—was successfully validated on all three platforms. A tea-preparation demonstration confirmed the system’s capability for coordinated multi-step service tasks. Future work will focus on implementing closed-loop feedback control using encoders or vision sensors to compensate for mechanical backlash and external disturbances, improving positional accuracy during high-speed and high-load operations.

REFERENCES

[1] S. Park, M. K. Park, J. Heo, J. S. Hwang, S. Hwang, D. Kim, S.-
J. Chung, and H. S. Kwak, “Robot versus human barista: Comparison of volatile compounds and consumers’ acceptance, sensory profile, and emotional response of brewed coffee,” Food Research International, vol. 172, p. 113119, 2023.
[2] A. Setiawan and A. Ma’arif, “Stirring system design for automatic coffee maker using OMRON PLC and PID control,” Int. J. Robotics and Control Systems, vol. 1, no. 1, pp. 1–8, 2021.
[3] M. Michalkova´ et al., “Automating the handling process of a coffee machine using a robotic manipulator,” in Proc. IEEE Int. Conf. Emerging Technologies and Factory Automation (ETFA), 2024.
[4] H. P. Nurba, D. Hadian, N. Lestari, K. A. Munastha, H. Mistialustina, and E. Rachmawati, “Performance evaluation of 3 DOF arm robot with forward kinematics Denavit–Hartenberg method for coffee maker machine,” in Proc. IEEE Int. Conf. Telecommunication Systems, Services, and Applications (TSSA), 2022.
[5] H. D. Salman, M. N. Hamzah, and S. H. Bakhy, “Kinematics analysis and implementation of three degrees of freedom robotic arm by using MATLAB,” The Iraqi Journal for Mechanical and Material Engineering, vol. 21, no. 2, pp. 118–129, 2021.
[6] M. A. Saad, M. H. Abdulaziz, A. K. Rahman, and A. Al-Fahad, “Development of an automated coffee preparation system using a robotic manipulator,” J. Mechatronics, Robotics, and Systems Programming, vol. 31, no. 38, pp. 45–52, 2024.
[7] A. Waluyo, A. Tafrikhatin, and S. R. Heri, “Robot arm design for coffee maker Arduino based,” in Proc. 2nd Borobudur Int. Symposium on Science and Technology (BIS-STE 2020), Atlantis Press, 2021, pp. 438– 442.
[8] J. J. Craig, Introduction to Robotics: Mechanics and Control, 3rd ed. Pearson Prentice Hall, 2005.
[9] B. Siciliano, L. Sciavicco, L. Villani, and G. Oriolo, Robotics: Modelling, Planning and Control. Springer, 2009.

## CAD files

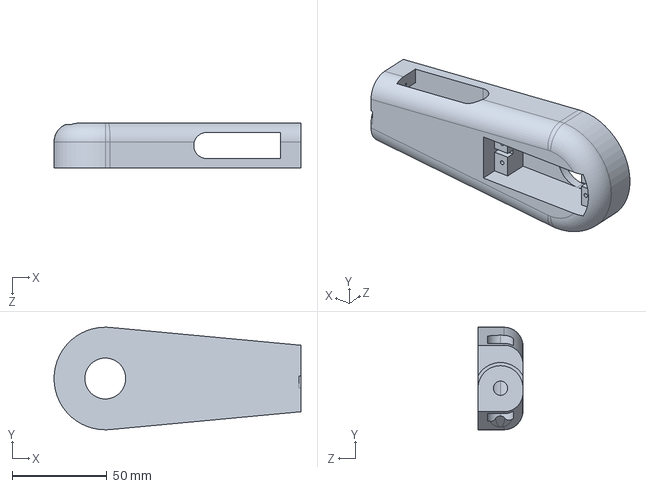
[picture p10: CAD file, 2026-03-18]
hardware/cad/Arm_2.STEP
130.0 x 54.0 x 23.7 mm

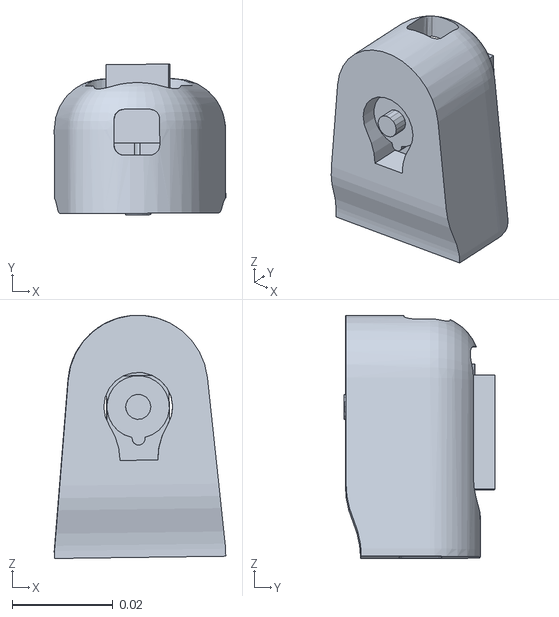
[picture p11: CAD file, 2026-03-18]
simulation/ros/src/my_robot_gazebo/meshes/Arm_3.STL
0.0341 x 0.0299 x 0.0483

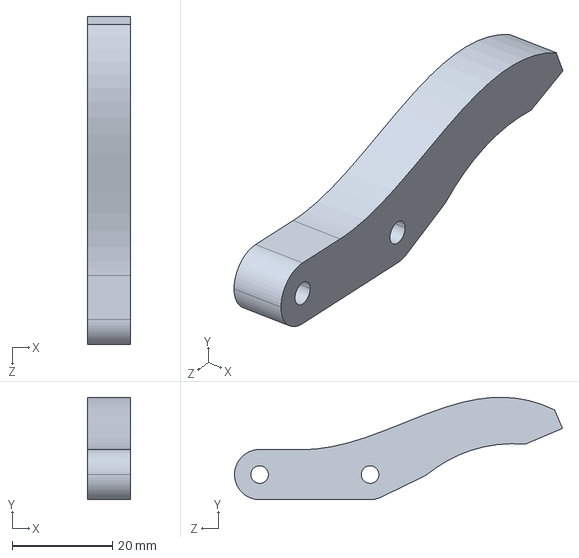
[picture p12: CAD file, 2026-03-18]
hardware/cad/Grip.STEP
8.50 x 20.4 x 65.3 mm

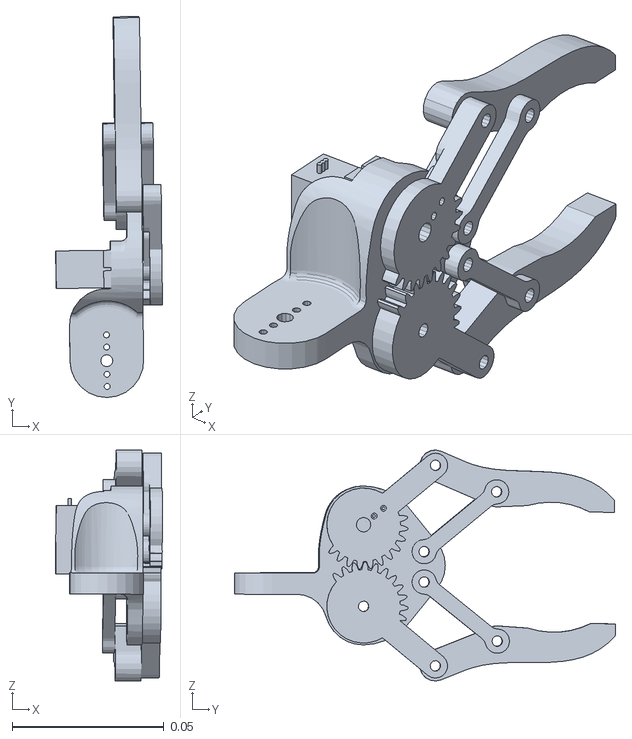
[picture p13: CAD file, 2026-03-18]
simulation/ros/src/my_robot_gazebo/meshes/Gripper.STL
0.0352 x 0.126 x 0.0761

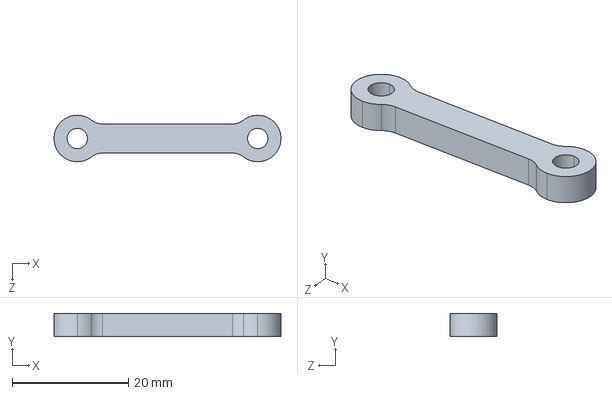
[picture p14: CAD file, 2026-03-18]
hardware/cad/Link.STEP
39.0 x 4.00 x 8.00 mm

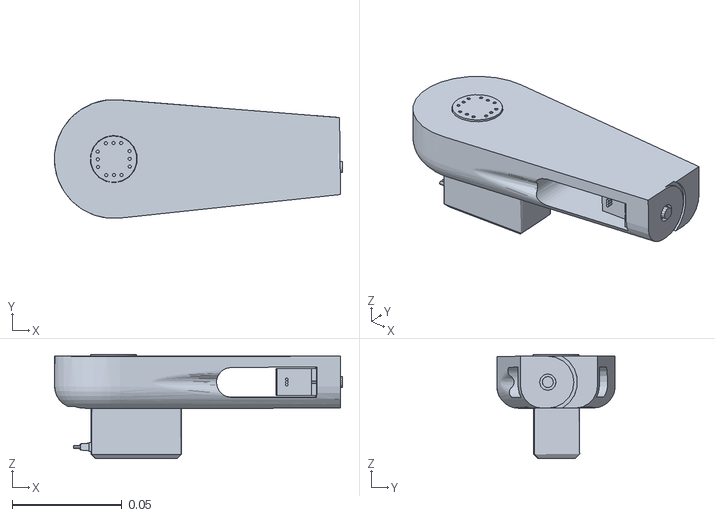
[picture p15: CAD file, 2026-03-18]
simulation/ros/src/my_robot_gazebo/meshes/Arm_2.STL
0.131 x 0.0539 x 0.0475

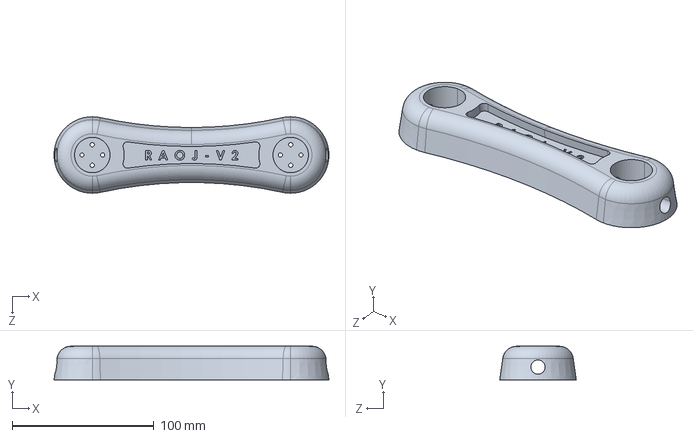
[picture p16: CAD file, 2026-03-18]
hardware/cad/Arm_1.STEP
194.0 x 23.7 x 54.0 mm

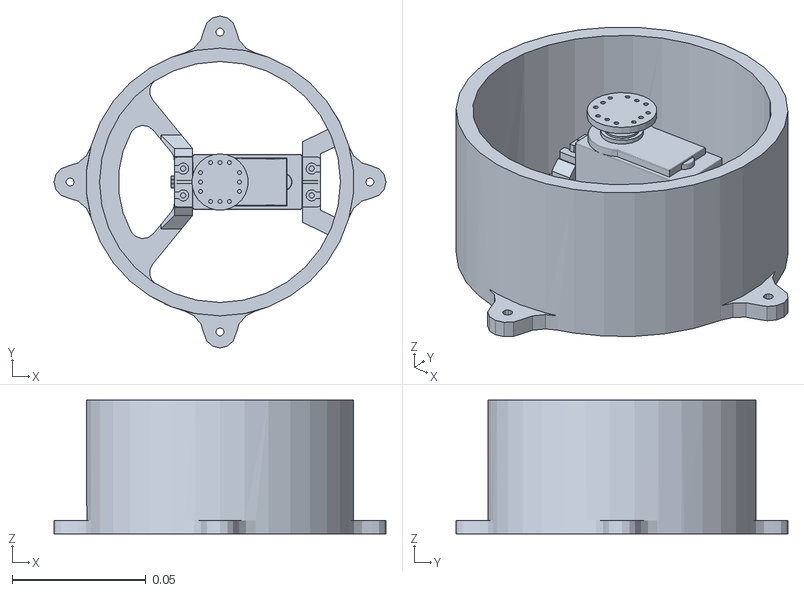
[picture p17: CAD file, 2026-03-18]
simulation/ros/src/my_robot_gazebo/meshes/Base_Link.STL
0.124 x 0.124 x 0.05

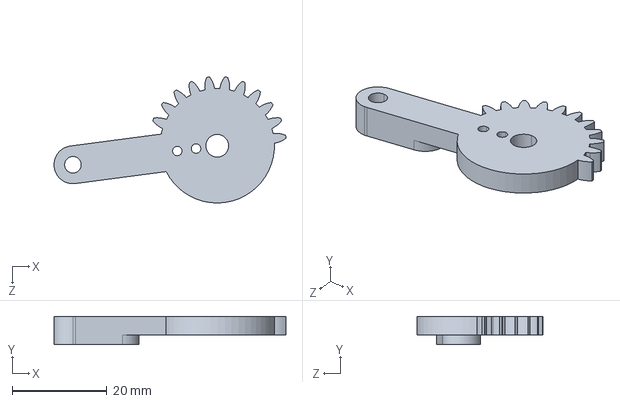
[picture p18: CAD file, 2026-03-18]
hardware/cad/Gear_Arm_2.STEP
49.0 x 6.00 x 26.6 mm

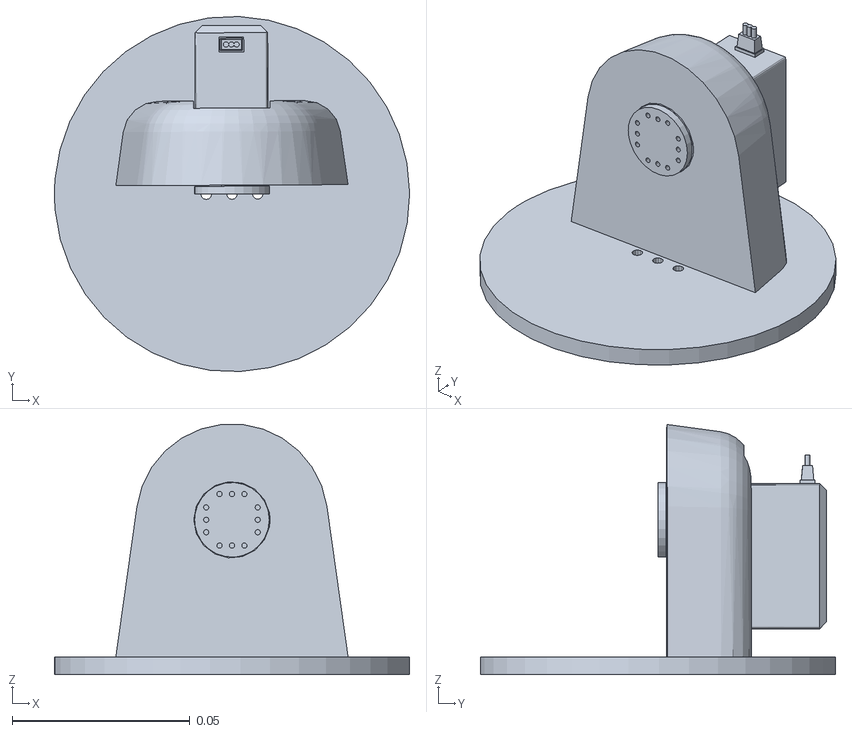
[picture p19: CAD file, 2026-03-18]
simulation/ros/src/my_robot_gazebo/meshes/Rotating_Waste.STL
0.1 x 0.0999 x 0.0704

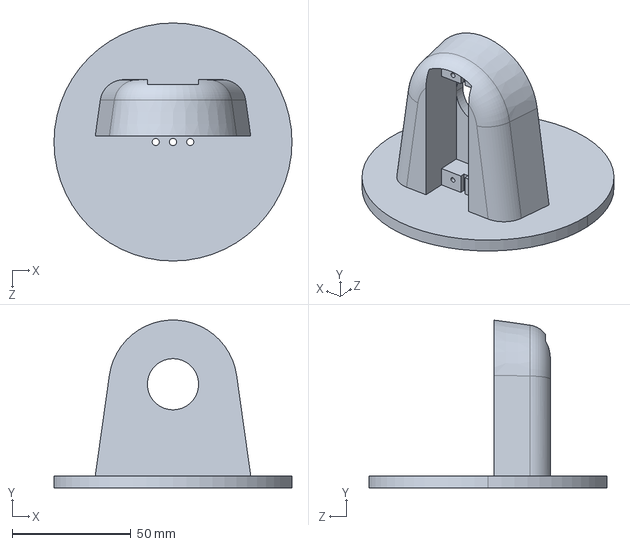
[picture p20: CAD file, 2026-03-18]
hardware/cad/Rotating_Waste.STEP
100.0 x 70.5 x 100.0 mm

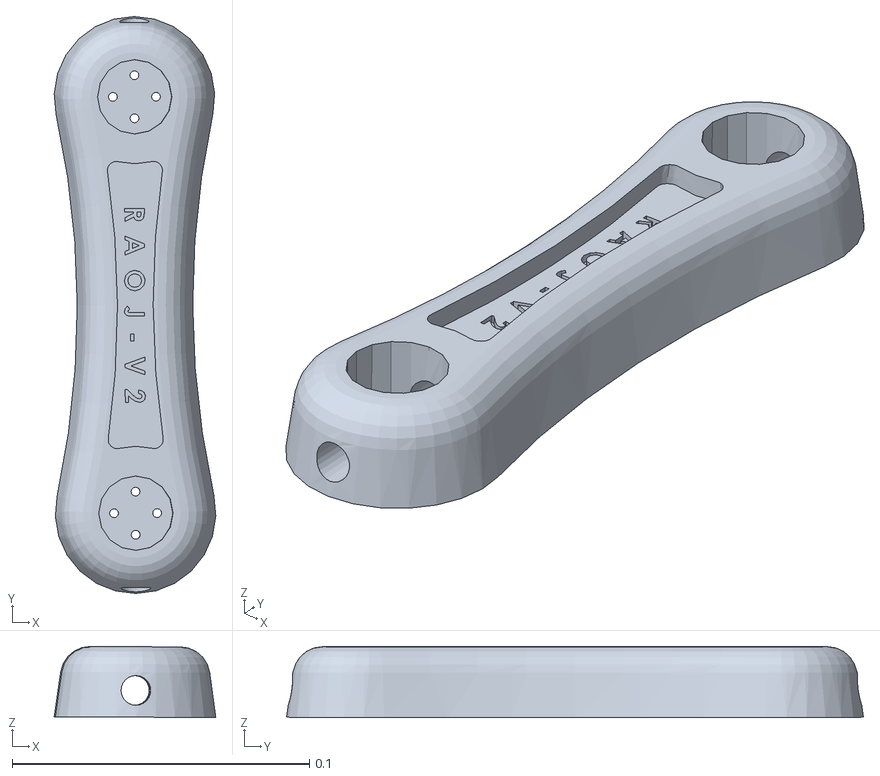
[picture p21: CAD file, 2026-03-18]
simulation/ros/src/my_robot_gazebo/meshes/Arm_1.STL
0.0544 x 0.194 x 0.0239

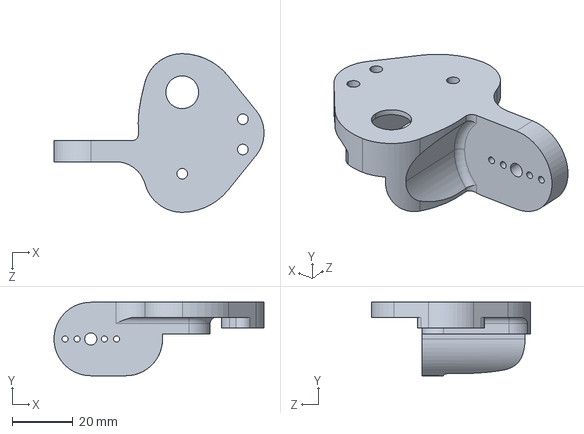
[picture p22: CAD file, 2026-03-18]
hardware/cad/Base.STEP
69.3 x 24.3 x 52.4 mm

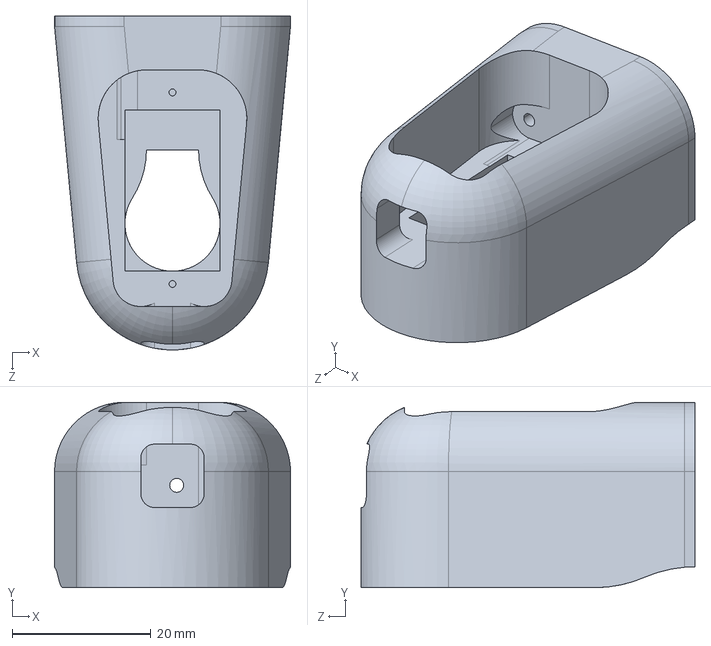
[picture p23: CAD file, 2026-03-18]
hardware/cad/Arm_3.STEP
34.0 x 26.7 x 48.1 mm

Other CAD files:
hardware/cad/5_DOF_Robot_Assembly.SLDASM
hardware/cad/Gear_Arm_1.STEP
hardware/cad/Servo_MG996R.STEP
hardware/cad/Microservo_horn.STEP
hardware/cad/Circular_Base.STEP
hardware/cad/Servo_Micro.STEP

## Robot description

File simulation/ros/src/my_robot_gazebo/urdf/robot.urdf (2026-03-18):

<?xml version="1.0" encoding="utf-8"?>
<robot name="R5_DOF_Robot_Assembly">

  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
  <link name="base_footprint"/>
  <joint name="base_footprint_to_Base_Link" type="fixed">
    <parent link="base_footprint"/>
    <child link="Base_Link"/>
    <origin xyz="0 0 0" rpy="0 0 0"/>
  </joint>

  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
  <link name="Base_Link">
   <inertial>
  <origin xyz="0 0 0" rpy="0 0 0"/>
  <mass value="0.8"/>
  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
</inertial>


    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
  </link>

 


  <link name="Rotating_Waste">
   <inertial>
  <origin xyz="0 0 0" rpy="0 0 0"/>
  <mass value="0.7"/>
  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
</inertial>


    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
  </link>

  <joint name="Joint_1" type="revolute">
    <origin xyz="0 0 0" rpy="0 0 0"/>
    <parent link="Base_Link"/>
    <child link="Rotating_Waste"/>
    <axis xyz="0 0 1"/>
    <limit lower="-3.14159" upper="3.14159" effort="200" velocity="2.0"/>
  <dynamics damping="3.0" friction="0.2"/>

  </joint>

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
  <link name="Arm_1">
  <inertial>
  <origin xyz="0 0 0" rpy="0 0 0"/>
  <mass value="0.6"/>
  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
</inertial>


    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
  </link>

  <joint name="Joint_2" type="revolute">
    <origin xyz="-2.7567E-05 0.0061999 0.04975" rpy="1.5708 0 0"/>
    <parent link="Rotating_Waste"/>
    <child link="Arm_1"/>
    <axis xyz="0 0 1"/>
   <limit lower="-3.14159" upper="3.14159" effort="200" velocity="2.0"/>
  <dynamics damping="3.0" friction="0.2"/>

  </joint>


  <link name="Arm_2">
  <inertial>
  <origin xyz="0 0 0" rpy="0 0 0"/>
  <mass value="0.5"/>
  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
</inertial>


    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
  </link>

  <joint name="Joint_3" type="revolute">
    <origin xyz="0 0.140 0.000" rpy="0 0 1.5708"/>
    <parent link="Arm_1"/>
    <child link="Arm_2"/>
    <axis xyz="0 0 -1"/>
    <limit lower="-3.14159" upper="3.14159" effort="200" velocity="2.0"/>
  <dynamics damping="3.0" friction="0.2"/>

  </joint>
  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


  <link name="Arm_3">
 <inertial>
  <origin xyz="0 0 0" rpy="0 0 0"/>
  <mass value="0.4"/>
  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
</inertial>


    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
  </link>

  <joint name="Joint_4" type="revolute">
    <origin xyz="0 0 0" rpy="-1.5708 0 -1.5708"/>
    <parent link="Arm_2"/>
    <child link="Arm_3"/>
    <axis xyz="0 0 -1"/>
   <limit lower="-3.14159" upper="3.14159" effort="200" velocity="2.0"/>
  <dynamics damping="3.0" friction="0.2"/>

  </joint>


  <link name="Gripper">
   <inertial>
  <origin xyz="0 0 0" rpy="0 0 0"/>
  <mass value="0.3"/>
  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
</inertial>


    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
  </link>

  <joint name="Joint_5" type="revolute">
    <origin xyz="-0.001651 -0.0054574 0.13289" rpy="1.5708 0 0"/>
    <parent link="Arm_3"/>
    <child link="Gripper"/>
    <axis xyz="0 0 1"/>
    <limit lower="-3.14159" upper="3.14159" effort="200" velocity="2.0"/>
  <dynamics damping="3.0" friction="0.2"/>

  </joint>
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
<link name="EE_frame">
  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
  <inertial>
    <origin xyz="0 0 0" rpy="0 0 0"/>
    <mass value="0.001"/>
    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
  </inertial>

  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
</link>

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
<joint name="EE_frame_lock" type="revolute">
  <parent link="Gripper"/>
  <child link="EE_frame"/>
  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
  <origin xyz="0.007 0.1 0.013" rpy="0 0 0"/>
  <axis xyz="1 0 0"/>
  <limit lower="0.0" upper="0.0" effort="1" velocity="0.1"/>
  <dynamics damping="1.0" friction="0.0"/>
</joint>

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




</robot>

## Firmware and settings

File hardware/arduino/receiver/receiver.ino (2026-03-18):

/*
 * Arduino Serial Receiver for Joint Control + Gripper
 * 
 * Accepts commands:
 * 1. "J1,J2,J3,J4" - Joint angles in degrees
 * 2. "GRIPPER_OPEN" - Opens the gripper
 * 3. "GRIPPER_CLOSE" - Closes the gripper
 * 
 * Flow:
 * 1. Waits for command
 * 2. Parses and executes
 * 3. Sends "READY" back to request next command
 */

#include <Servo.h>

// ============================================
// CONFIGURATION
// ============================================
const int SERVO_PINS[5] = {3, 5, 6, 9, 10};  // Joints 1-4 + Gripper (Joint 5)
Servo servos[5];

// ============================================
// GRIPPER SAFETY CONFIGURATION
// ============================================
// IMPORTANT: Gripper motor must NOT be fully closed to prevent overload!
// 
// Gripper Joint Angles (degrees):
//   - GRIPPER_OPEN = 90.0°    → Servo Position: 180° (fully open)
//   - GRIPPER_CLOSED = 15.0°  → Servo Position: 105° (TIGHTER grip for better hold)
// 
// Adjusted to 15.0° for tighter grip while maintaining motor safety
const float GRIPPER_OPEN = 90.0;    // Fully open → Servo: 180°
const float GRIPPER_CLOSED = 30.0;  // TIGHTER closing position → Servo: 105°

// Maximum safe closing limit for gripper (safety check)
const float GRIPPER_MIN_SAFE = 30.0;  // Minimum angle to prevent motor overload

// Buffer for incoming serial data
String inputString = "";
bool stringComplete = false;

// ============================================
// SETUP
// ============================================
void setup() {
  Serial.begin(115200); // Fast baud rate for smooth streaming
  while (!Serial) { }

  // Attach Servos
  for (int i = 0; i < 5; i++) {
    servos[i].attach(SERVO_PINS[i]);
  }

  // Move to a safe "home" position initially (optional)
  // jointToServo(0, 0); ... etc

  Serial.println("ARDUINO_CONNECTED"); // Handshake signal
}

// ============================================
// MAIN LOOP
// ============================================
void loop() {
  // 1. Process data if a new line has arrived
  if (stringComplete) {
    parseAndMove(inputString);
    
    // Clear buffer for next command
    inputString = "";
    stringComplete = false;
    
    // Tell laptop we are ready for the next line
    Serial.println("READY");
  }
}

// ============================================
// SERIAL EVENT (Interrupt-like)
// ============================================
/*
  SerialEvent occurs whenever a new data comes in the hardware serial RX. 
  This runs between each time loop() runs.
*/
void serialEvent() {
  while (Serial.available()) {
    char inChar = (char)Serial.read();
    
    // Check for newline character which marks end of command
    if (inChar == '\n') {
      stringComplete = true;
    } else {
      inputString += inChar;
    }
  }
}

// ============================================
// PARSING AND MOVEMENT LOGIC
// ============================================
void parseAndMove(String data) {
  // Check for special gripper commands
  if (data == "GRIPPER_OPEN") {
    Serial.println(">>> Opening gripper...");
    int servoPos = jointToServo(GRIPPER_OPEN, 4);
    servos[4].write(servoPos);
    delay(1000);  // Wait for gripper to open
    return;
  }
  
  if (data == "GRIPPER_CLOSE") {
    Serial.println(">>> Closing gripper to TIGHT position...");
    Serial.print("    Joint angle: ");
    Serial.print(GRIPPER_CLOSED);
    Serial.print("° -> Servo: ");
    int servoPos = jointToServo(GRIPPER_CLOSED, 4);
    Serial.print(servoPos);
    Serial.println("°");
    servos[4].write(servoPos);
    delay(1000);  // Wait for gripper to close
    return;
  }
  
  // Expected format: "val1,val2,val3,val4"
  // We use standard C string parsing (strtok) for efficiency
  
  char buf[data.length() + 1];
  data.toCharArray(buf, sizeof(buf));
  
  float angles[4];
  char *ptr = strtok(buf, ",");
  int index = 0;
  
  while (ptr != NULL && index < 4) {
    angles[index] = atof(ptr); // Convert string to float
    ptr = strtok(NULL, ",");
    index++;
  }

  // If we didn't get 4 angles, ignore this bad packet
  if (index < 4) return;

  // Apply Calibration and Move Servos (Joints 1-4 only)
  for (int i = 0; i < 4; i++) {
    int servoPos = jointToServo(angles[i], i);
    servos[i].write(servoPos);
  }
}

// ============================================
// CALIBRATION FUNCTION WITH GRIPPER SAFETY
// ============================================
int jointToServo(float joint_deg, int joint_index) {
  float servo_deg;
  
  switch(joint_index) {
    case 0:  // Joint 1: Offset +90
      servo_deg = joint_deg + 90.0;
      break;
    case 1:  // Joint 2: Inverted + 110 offset
      servo_deg = -1.0 * joint_deg + 110.0;
      break;
    case 2:  // Joint 3: Inverted + 90 offset
      servo_deg = -1.0 * joint_deg + 90.0;
      break;
    case 3:  // Joint 4: Inverted + 110 offset
      servo_deg = -1.0 * joint_deg + 110.0;
      break;
    case 4:  // Joint 5 (Gripper): Direct mapping + 90, with SAFETY CHECK
      // SAFETY: Prevent gripper from closing too much
      if (joint_deg < GRIPPER_MIN_SAFE) {
        Serial.print("!!! WARNING: Gripper angle ");
        Serial.print(joint_deg);
        Serial.print("° is below safe minimum ");
        Serial.print(GRIPPER_MIN_SAFE);
        Serial.println("°. Clamping to safe value!");
        joint_deg = GRIPPER_MIN_SAFE;
      }
      servo_deg = joint_deg + 90.0;
      break;
    default:
      servo_deg = 90.0;
  }
  
  // Clamp to valid servo range
  if (servo_deg < 0) servo_deg = 0;
  if (servo_deg > 180) servo_deg = 180;
  
  return (int)servo_deg;
}

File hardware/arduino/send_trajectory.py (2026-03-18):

import serial
import time
import csv
import sys

# ================= CONFIGURATION =================
SERIAL_PORT = '/dev/cu.usbserial-110'      # WINDOWS: 'COM3', 'COM4', etc.
                          # LINUX/MAC: '/dev/ttyUSB0' or '/dev/ttyACM0'
BAUD_RATE = 115200        # Must match Arduino
CSV_FILE_1 = 'csv_files/trajectory_data_combined_1_square1.csv'  # First trajectory - Square 1
CSV_FILE_2 = 'csv_files/trajectory_data_combined_2_square2.csv'  # Second trajectory - Square 2
CSV_FILE_3 = 'csv_files/trajectory_data_combined_3_square2_rev.csv'  # Third trajectory - Square 2 Reverse
CSV_FILE_5 = 'csv_files/trajectory_data_combined_4_transition.csv'  # Fourth trajectory - Transition
CSV_FILE_4 = 'csv_files/trajectory_data_combined_5_circle.csv'  # Fifth trajectory - Circle
DELAY_BETWEEN_POINTS = 0.1 # Seconds (matches your old 100ms delay)
CIRCLE_DELAY = 0.05 # Faster delay for circle trajectory (50ms)

# Gripper Control
GRIPPER_OPEN_CMD = "GRIPPER_OPEN\n"
GRIPPER_CLOSE_CMD = "GRIPPER_CLOSE\n"
# =================================================

def send_gripper_command(ser, command_name, command):
    """Send a gripper command and wait for acknowledgment."""
    print(f"\n>>> {command_name}...")
    ser.write(command.encode('utf-8'))

    # Wait for READY acknowledgment
    while True:
        response = ser.readline().decode('utf-8').strip()
        if response:
            print(f"    Arduino: {response}")
        if "READY" in response:
            break

def send_trajectory_point(ser, vals, point_num, total, delay=None):
    """Send a single trajectory point and wait for acknowledgment."""
    if delay is None:
        delay = DELAY_BETWEEN_POINTS

    msg = f"{vals[0]},{vals[1]},{vals[2]},{vals[3]}\n"
    ser.write(msg.encode('utf-8'))

    # Log progress
    sys.stdout.write(f"\rSending Point {point_num}/{total}: {msg.strip()}   ")
    sys.stdout.flush()

    # Wait for acknowledgment
    while True:
        response = ser.readline().decode('utf-8').strip()
        if "READY" in response:
            break

    time.sleep(delay)

def main():
    try:
        # Open Serial Connection
        ser = serial.Serial(SERIAL_PORT, BAUD_RATE, timeout=1)
        time.sleep(2) # Wait for Arduino to reset
        print(f"Connected to {SERIAL_PORT}")

        # Wait for handshake
        print("Waiting for Arduino boot...")
        while True:
            line = ser.readline().decode('utf-8').strip()
            if "ARDUINO_CONNECTED" in line:
                print("Arduino is online!")
                break

        # ========================================
        # LOAD ALL CSV FILES
        # ========================================
        print("\n" + "="*50)
        print("LOADING TRAJECTORY FILES")
        print("="*50)

        # Load Square 1
        with open(CSV_FILE_1, 'r') as f:
            square1_data = [row for row in csv.reader(f) if len(row) >= 4]
        print(f"Square 1: Loaded {len(square1_data)} points from {CSV_FILE_1}")

        # Load Square 2
        with open(CSV_FILE_2, 'r') as f:
            square2_data = [row for row in csv.reader(f) if len(row) >= 4]
        print(f"Square 2: Loaded {len(square2_data)} points from {CSV_FILE_2}")

        # Load Square 2 Reverse
        with open(CSV_FILE_3, 'r') as f:
            square2_reverse_data = [row for row in csv.reader(f) if len(row) >= 4]
        print(f"Square 2 Reverse: Loaded {len(square2_reverse_data)} points from {CSV_FILE_3}")

        # Load Transition Trajectory
        with open(CSV_FILE_5, 'r') as f:
            transition_data = [row for row in csv.reader(f) if len(row) >= 4]
        print(f"Transition: Loaded {len(transition_data)} points from {CSV_FILE_5}")

        # Load Circle
        with open(CSV_FILE_4, 'r') as f:
            circle_data = [row for row in csv.reader(f) if len(row) >= 4]
        print(f"Circle: Loaded {len(circle_data)} points from {CSV_FILE_4}")

        if len(square1_data) == 0 or len(square2_data) == 0 or len(square2_reverse_data) == 0 or len(transition_data) == 0 or len(circle_data) == 0:
            print("ERROR: One or more CSV files are empty!")
            return

        # ========================================
        # SQUARE 1: PICK AND MOVE
        # ========================================
        print("\n" + "="*50)
        print("EXECUTING SQUARE 1: PICK AND MOVE")
        print("="*50)

        # STEP 1: Open Gripper
        send_gripper_command(ser, "Opening Gripper", GRIPPER_OPEN_CMD)

        # STEP 2: Move to First Position (Pickup Position)
        print("\n>>> Moving to pickup position (first point)...")
        try:
            vals = [float(x) for x in square1_data[0][:4]]
            send_trajectory_point(ser, vals, 1, len(square1_data))
        except ValueError:
            print("ERROR: Invalid first position in Square 1")
            return

        # Wait 1 second for robot to stabilize at pickup position
        print("\nWaiting for robot to stabilize...")
        time.sleep(1.0)

        # STEP 3: Close Gripper (Grab Item)
        send_gripper_command(ser, "Closing Gripper to Grab Item", GRIPPER_CLOSE_CMD)

        # STEP 4: Execute Remaining Square 1 Trajectory (with gripper closed)
        print("\n>>> Executing Square 1 trajectory with item...")
        for i, row in enumerate(square1_data[1:], start=2):
            try:
                vals = [float(x) for x in row[:4]]
                send_trajectory_point(ser, vals, i, len(square1_data))
            except ValueError:
                print(f"\nSkipping invalid row in Square 1: {row}")

        # STEP 5: Open Gripper (Release Item)
        print("\n")
        send_gripper_command(ser, "Opening Gripper to Release Item", GRIPPER_OPEN_CMD)

        # ========================================
        # SQUARE 2: MOVE AND PLACE
        # ========================================
        print("\n" + "="*50)
        print("EXECUTING SQUARE 2: MOVE AND PLACE")
        print("="*50)

        # STEP 6: Execute ALL Square 2 Points (with gripper OPEN)
        print("\n>>> Executing Square 2 trajectory with gripper open...")
        for i, row in enumerate(square2_data, start=1):
            try:
                vals = [float(x) for x in row[:4]]
                send_trajectory_point(ser, vals, i, len(square2_data))
            except ValueError:
                print(f"\nSkipping invalid row in Square 2: {row}")

        # STEP 7: Wait 1 second at final position
        print("\nWaiting for robot to stabilize at placement position...")
        time.sleep(1.0)

        # STEP 8: Close Gripper (Place Item)
        print("\n")
        send_gripper_command(ser, "Closing Gripper to Place Item", GRIPPER_CLOSE_CMD)

        # ========================================
        # SQUARE 2 REVERSE: RETURN WITH GRIPPER CLOSED
        # ========================================
        print("\n" + "="*50)
        print("EXECUTING SQUARE 2 REVERSE: RETURN PATH")
        print("="*50)
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

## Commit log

2026-03-18 Polish repo for publication
    - Add figures extracted from IEEE paper (9 images)
    - Fix DH parameters across MATLAB and Python scripts
    - Overhaul README with visuals, TOC, and structured sections
    - Add sub-READMEs for MATLAB and CAD directories
    - Add GitHub Actions CI (ruff linter)
    - Clean up Python scripts (lint, imports, formatting)
    [send_trajectory.py]
2026-03-19 Update README structure tree to include Proteus circuit simulation file
